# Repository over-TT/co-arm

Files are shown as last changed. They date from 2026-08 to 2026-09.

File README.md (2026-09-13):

# co-arm

3D-printed four-joint camera arm that Codex can see through and move.

A Raspberry Pi handles the camera and commands. An ESP32 Arm HAT talks to four
serial servos. The Base turns through a 4:1 set of 3D-printed gears.

**Status:** working prototype. Codex has moved the real arm and captured the
desk through its camera. The dashboard, Pi code, ESP32 firmware, simulator,
Codex tools, and 12 printable parts are here. The last build details and public
demo media are still coming.

## Start here

- **Try the software:** [open the dashboard without hardware](docs/QUICKSTART.md).
- **Connect an existing arm:** [check the setup and connect it](docs/SETUP_WITH_CODEX.md#existing-arm-short-path).
- **Build your own:** start with the [parts and assembly guide](docs/ASSEMBLY.md).
  The bearing, fastener, print, wiring, and power details still need finishing.
- **See what is proven:** [status and evidence](docs/STATUS.md),
  [known limitations](docs/KNOWN_LIMITATIONS.md).

---

## Why I built it this way

I wanted Codex to do something physical, not just spit out servo angles. It
should be able to look at my desk, work out a move, move the arm, then look
again and see what happened.

The Pi handles the camera and the bigger commands. The ESP32 stays close to the
servos and handles the fast communication. The dashboard and Codex use the same
route to the arm, so I can test a move myself and let Codex use the exact same
system.

The Base uses a 4:1 gear set I printed. It trades some speed for more output
torque and finer movement. An early version tracked the Base by adding up
relative moves. That eventually lost the real position, so I switched to the
servo's own absolute multi-turn reading and kept a physical zero mark.

That failure shaped the rest of the project too: show the move first, run it,
then read the joints and camera again. Less guessing, more checking what the
real arm actually did.

---

## The build

| Part | Reference build |
| --- | --- |
| Joints | Base, Shoulder, Elbow, and Camera |
| Main servos | 3 x ST3215/STS-family serial-bus servos |
| Camera servo | SC09/SCS-family serial-bus servo |
| Base drive | 3D-printed 4:1 gear reduction |
| Main computer | Raspberry Pi 4 |
| Servo controller | ESP32 on Waveshare Bus Servo Driver HAT (A) |
| Camera | Raspberry Pi Camera Module 3 Wide / IMX708 |
| Arm lengths | 180 mm upper arm, 220 mm elbow-to-camera tip |
| Arm HAT firmware | `arm-hat-2.7.2` |

The Camera joint only aims the sensor. Shoulder and Elbow place it. Base turns
the whole arm around the desk.

---

## How it works

```mermaid
flowchart LR
    USER["Dashboard or Codex"] --> PI["Raspberry Pi"]
    PI --> CAM["Camera"]
    PI --> HAT["ESP32 Arm HAT"]
    HAT --> SERVOS["Four serial servos"]
    SERVOS --> HAT
    SIM["Isaac Sim"] -. same arm interface .-> USER
```

The dashboard and Codex both send moves to the Pi. The Pi works out the joint
targets and passes them to the ESP32. The ESP32 talks to the servos and sends
their positions back. The camera gives a separate look at what happened.

Codex gets useful arm actions such as **look**, **preview**, **move**, and
**release**. It does not need to build raw servo packets or know register
addresses. A preview does not move anything; it just shows the planned joint
targets and path before they are sent.

The simulator uses the same general route, so most of the software can be run
without the real arm connected.

---

## Repo

- [`software/dashboard/`](software/dashboard/) — the standalone arm dashboard.
- [`software/python/robot_gateway/`](software/python/robot_gateway/) — the Pi
  code for the arm and camera.
- [`software/firmware/`](software/firmware/) — the ESP32 Arm HAT firmware.
- [`software/python/arm_mcp/`](software/python/arm_mcp/) and
  [`software/plugin/`](software/plugin/) — the tools Codex uses to work with
  the arm.
- [`software/python/arm_sim/`](software/python/arm_sim/) — the Isaac Sim model
  and simulator bridge.
- [`software/operations/`](software/operations/) — setup, deployment, status,
  recovery, and build scripts.
- [`hardware/3mf/`](hardware/3mf/) — all 12 current printed parts, including
  both Base gears, the arm links, servo mounts, and camera pieces.
- [`hardware/`](hardware/README.md) — BOM and the rest of the mechanical and
  electrical build files.
- [`docs/`](docs/README.md) — setup, build notes, history, troubleshooting, and
  deeper technical details.
- [`docs/SETUP_WITH_CODEX.md`](docs/SETUP_WITH_CODEX.md) — the full path from a
  clean checkout to simulation or a real arm.

[`software/SOURCE_INDEX.json`](software/SOURCE_INDEX.json) is the quick map for
an agent or developer looking for a particular piece of source.

---

## Run it

The [quickstart](docs/QUICKSTART.md) gets the dashboard running locally with
Python, Node, and pnpm. You can explore it before connecting an arm; movement
and camera controls need a configured gateway.

For the next step, use the full setup guide:

- [Run the source checks](docs/SETUP_WITH_CODEX.md#1-clone-and-validate-without-hardware).
- [Run the Isaac Sim arm](docs/SETUP_WITH_CODEX.md#3-run-the-isaac-sim-arm).
- [Connect an existing real arm](docs/SETUP_WITH_CODEX.md#existing-arm-short-path).

Isaac Sim and the ESP32 build tools are separate installs. The dashboard does
not include a fake camera feed or a simulator that runs in the browser.

---

## Put Codex on it

Open the repo in Codex and paste this:

```text
Help me run co-arm. Read AGENTS.md and docs/SETUP_WITH_CODEX.md first. Check
whether I am using source only, Isaac Sim, or the real arm, then take the
matching path. For a configured real arm, read its current state, show the move,
run it, and check the joints or camera afterward. Treat the physical task I ask
for as the go-ahead for its normal steps. Keep updates short and stop only if a
real fault or missing physical fact changes the job.
```

The external MCP/plugin is the supported Codex connection. It talks to the same
Pi arm service as the dashboard.

---

## Build the real arm

Start with [`docs/ASSEMBLY.md`](docs/ASSEMBLY.md) and
[`docs/COMMISSIONING.md`](docs/COMMISSIONING.md).

The short version:

1. print and assemble the mechanism, including the 4:1 Base gears;
2. wire the Pi, camera, Arm HAT, and four servos;
3. give every servo the correct ID;
4. mark the physical Base zero;
5. calibrate one joint at a time;
6. test small moves before coordinated motion;
7. connect the dashboard or Codex after the arm works normally.

The reference software and all 12 current printable parts are included. To
finish the build package, I still need to add:

- the large Base bearing details;
- final print settings and the screw/insert list;
- an as-built wiring diagram and pinout;
- the final power details;
- assembly photos, a hero photo, and a short real-arm demo.

See [`docs/STATUS.md`](docs/STATUS.md) for what has actually been checked on the
reference arm.

---

## License

Made by [over-TT](https://github.com/over-TT). Available for noncommercial use:

- **Software and firmware:** [PolyForm Noncommercial 1.0.0](LICENSE).
- **Printable designs, documentation, and media:** [CC BY-NC 4.0](LICENSES/CC-BY-NC-4.0.txt).

Commercial use requires separate permission. See [Licensing](LICENSING.md) for
the exact scope, attribution, and third-party terms. This is source-available
software, not an OSI open-source release.

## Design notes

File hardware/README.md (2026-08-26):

# Hardware files

This directory is the landing area for the co-arm physical design package.

```text
hardware/
|-- bom/                  Exact purchased and manufactured parts
|-- cad/
|   |-- native/           Editable source CAD
|   `-- step/             Neutral solid exports
|-- 3mf/                  Current 3D-printed parts
|-- stl/
|   `-- print-ready/      Verified, intentionally oriented print candidates
|-- drawings/             Dimensioned part and assembly drawings
`-- electronics/
    |-- schematics/       Electrical intent and power distribution
    `-- wiring/           Point-to-point harness and connector documentation
```

Start with [`../docs/HARDWARE.md`](../docs/HARDWARE.md), then follow the export
and naming rules in [`../docs/CAD_AND_STL.md`](../docs/CAD_AND_STL.md).

## When adding more build files

1. Add label photographs and use them to finish `bom/bom.csv`.
2. Put new printed parts in `3mf/` with the same clean naming style.
3. Add editable CAD to `cad/native/`.
4. Export the matching revision to `cad/step/`.
5. Export printable parts to `stl/`; promote only checked parts to
   `stl/print-ready/`.
6. Add revision-matched drawings to `drawings/`.
7. Add electrical source files and readable exports to
   `electronics/schematics/` and `electronics/wiring/`.
8. Update the assembly documentation only after checking the files against the
   physical arm.

Do not add credentials, local network addresses, private filesystem paths,
unwanted serial numbers, or personal metadata. Do not add a license or
third-party attribution unless ownership and the exact terms have been
confirmed.

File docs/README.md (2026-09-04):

# Documentation map

## Start here

- [Quickstart: open the dashboard without hardware](QUICKSTART.md)
- [Connect an existing arm](SETUP_WITH_CODEX.md#existing-arm-short-path)
- [Full setup runbook, with or without Codex](SETUP_WITH_CODEX.md)
- [Status and evidence](STATUS.md)
- [Open questions](OPEN_QUESTIONS.md)
- [Known limitations](KNOWN_LIMITATIONS.md)
- [Release checklist](RELEASE_CHECKLIST.md)
- [Release review and remaining blockers](RELEASE_REVIEW.md)
- [Release notes and X draft](LAUNCH_DRAFT.md)
- [Owner handoff](OWNER_HANDOFF.md)

For a new physical build, start with [Assembly](ASSEMBLY.md), the
[hardware inventory](HARDWARE.md), and [Commissioning](COMMISSIONING.md).
The printable parts are included; the remaining build gaps are listed in
[Known limitations](KNOWN_LIMITATIONS.md).

## Build and hardware

- [Hardware inventory](HARDWARE.md)
- [Mechanical design](MECHANICAL.md)
- [Electronics and power](ELECTRONICS.md)
- [Assembly](ASSEMBLY.md)
- [CAD and STL exports](CAD_AND_STL.md)
- [Commissioning](COMMISSIONING.md)

## Software and operation

- [Software architecture](SOFTWARE_ARCHITECTURE.md)
- [Control and safety](CONTROL_AND_SAFETY.md)
- [Codex integration](CODEX_INTEGRATION.md)
- [AI context contract](AI_CONTEXT.md)
- [Vision workflow](VISION.md)
- [Troubleshooting](TROUBLESHOOTING.md)
- [Public source boundary](SOURCE_RELEASE_PLAN.md)

## Project record

- [Public engineering history](HISTORY.md)
- [Proof log](PROOF_LOG.md)
- [Roadmap](ROADMAP.md)
- [Media guide](MEDIA_GUIDE.md)
- [Provenance and privacy](PROVENANCE.md)

For the project record and the exact boundary between publishable evidence and
local runtime data, use [History](HISTORY.md) and
[Provenance and privacy](PROVENANCE.md).

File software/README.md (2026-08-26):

# ARM software

This is the executable, ARM-only source boundary. Its project root is this
`software/` directory; runtime state belongs in ignored `software/runtime/`.

| Folder | Contents |
| --- | --- |
| `dashboard/` | Standalone Vite/React Control Center, calibration, camera, and bounded Live Follow |
| `python/web_backend/` | Loopback-only FastAPI host and explicit SIM/REAL routing |
| `python/robot_gateway/` | Raspberry Pi gateway, camera, serial controller, calibration, motion policy, and tests |
| `python/arm_sim/` | Core authenticated Isaac bridge, digital-twin assets, viewer, gateway, and tests |
| `python/arm_mcp/` | Typed ARM MCP server |
| `firmware/` | Arm HAT firmware/library, protocol fixtures, and host tests |
| `operations/` | Parameterized deployment, recovery, status, service, firmware-build, and simulator helpers |
| `plugin/` | Repo-local Codex marketplace, setup/runtime skills, and machine-local MCP setup guidance |

[`SOURCE_INDEX.json`](SOURCE_INDEX.json) maps the canonical entrypoints.
[`SOURCE_MANIFEST.json`](SOURCE_MANIFEST.json) records every releasable software
file and digest; regenerate it from the repository root with
`python tools/build_source_manifest.py` after an intentional source change.

Quick verification from the repository root:

```powershell
python -m venv .venv
.\.venv\Scripts\python.exe -m pip install --requirement ".\software\python\requirements.lock"
.\.venv\Scripts\python.exe -m pip install --no-deps --editable ".\software\python"

Set-Location software\python
..\..\.venv\Scripts\python.exe -m pytest -q -p no:cacheprovider
..\..\.venv\Scripts\python.exe -m pytest -q -p no:cacheprovider ..\firmware\tests\test_arm_hat_controller_v1.py

Set-Location ..\dashboard
pnpm install --frozen-lockfile
pnpm test
pnpm build
Set-Location ..\..
```

Run the dashboard with `.\.venv\Scripts\python.exe -m web_backend`. A clean
checkout starts without a physical or simulated gateway; pass an explicit
loopback URL and local token-file pair to enable one. The supported agent path
is the repository contract plus external plugin; Codex binaries, authentication,
installed plugin configuration, live credentials, retained frames, databases,
device backups, generated scenes, and toolchains are deliberately not bundled.

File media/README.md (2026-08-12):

# Media

Only reviewed, public-safe exports belong in this tracked tree.

- `photos/overview/` — complete-arm and scale views.
- `photos/assembly/` — staged construction and cable-routing views.
- `photos/details/` — labels, joints, gearing, camera, HAT, and power details.
- `diagrams/` — original SVG/PNG diagrams and captions.
- `video/` — small approved clips or link manifests.
- `raw/` — ignored intake folder for unreviewed originals; create it locally.

Follow [`docs/MEDIA_GUIDE.md`](../docs/MEDIA_GUIDE.md). Remove metadata and
review faces, screens, addresses, serials, QR codes, and unrelated desk details
before copying anything out of `raw/`.

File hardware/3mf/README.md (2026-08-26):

# 3D-printed parts

These are the parts from my current arm.

## Parts

- `co-arm_base_main-body_r01.3mf` — Base with the large gear built in.
- `co-arm_base_servo-gear_r01.3mf` — Small gear for the Base servo.
- `co-arm_base_bearing-bottom_r01.3mf` — Sits underneath the large Base bearing.
- `co-arm_base_shaft-base_r01.3mf` — Sits on top of the bearing.
- `co-arm_base_level-2-platform_r01.3mf` — Bolts to the Shaft Base and carries the lower-arm servo.
- `co-arm_shoulder_servo-mount_r01.3mf` — Mount for the lower-arm servo.
- `co-arm_shoulder_lower-link_r01.3mf` — Lower arm link.
- `co-arm_elbow_upper-link_r01.3mf` — Upper arm link.
- `co-arm_elbow_servo-cover_r01.3mf` — Cover for the top servo.
- `co-arm_camera_servo-mount_r01.3mf` — Holds the camera servo at the end of the arm.
- `co-arm_camera_holder_r01.3mf` — Holds the camera.
- `co-arm_camera_cover_r01.3mf` — Closes the camera holder.

## Build order

1. Put the bearing-bottom piece in the Base.
2. Fit the large bearing above it.
3. Put the Shaft Base on the bearing.
4. Fit the lower-arm servo and its mount before bolting on the Level 2 platform.
5. Mesh the small servo gear with the large Base gear.
6. Add the lower link, upper link, and top-servo cover.
7. Fit the camera-servo mount, camera holder, camera, and camera cover.

## Still needed

- large bearing details;
- heat-set insert and M3 screw list;
- print settings;
- assembly photos.

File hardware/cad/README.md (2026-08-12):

# CAD

Store editable sources in [`native/`](native/) and neutral solid exports in
[`step/`](step/). Do not mix STL meshes, slicer projects, drawings, or firmware
into these folders.

Follow [`../../docs/CAD_AND_STL.md`](../../docs/CAD_AND_STL.md) for the required
millimetre units, coordinate frame, naming, `rNN` revisions, STEP settings, and
matched-export checklist.

Minimum release set:

- top-level zero-position assembly;
- one file/component per manufactured part;
- purchased actuator/controller reference geometry where licensing permits;
- named Base, Shoulder, Elbow, and Camera axes;
- named work-surface and tool/camera datums;
- revision-matched STEP and drawings.

Do not infer ownership or apply a license to imported vendor models until their
source and terms are documented.

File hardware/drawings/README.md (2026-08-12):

# Mechanical drawings

Put revision-matched part and assembly drawings here. Prefer a readable PDF for
every released drawing and include the editable/source drawing when available.

Use the same basename as CAD:

```text
co-arm_<subsystem>_<part-name>[_<variant>]_rNN.pdf
```

Part drawings should state units, projection, material/process when confirmed,
datums, overall and fit-critical dimensions, holes/threads/inserts, tolerances,
orientation, and quantity. Assembly drawings should add exploded views, BOM
balloons, fastener stack order, joint zero views, gear timing/mesh, and cable
routing.

Do not invent material, tolerance, fastener, or torque values. Leave an explicit
`TODO (owner verification)` note until the as-built part is inspected.

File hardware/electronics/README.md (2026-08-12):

# Electronics design files

This folder separates electrical intent from physical harness construction:

- [`schematics/`](schematics/) — power domains, protection, interfaces, and
  connector pin definitions;
- [`wiring/`](wiring/) — point-to-point cables, connector orientation, wire
  gauge/color/length, labels, and routing.

Read [`../../docs/ELECTRONICS.md`](../../docs/ELECTRONICS.md) first. The current
repository does not yet contain a verified pinout. Do not infer wiring from
software signal names, connector shape, or wire color.

The candidate 12 V, 7.5 A supply, camera-servo voltage/regulator, fusing,
grounding, polarity, wire ratings, and hardware E-stop/disconnect all require
owner verification before a reproducible wiring guide can be released.

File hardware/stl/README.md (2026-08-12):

# STL exports

Put revision-matched printable-part meshes here. STL has no dependable unit
metadata, so every mesh must be exported numerically in **millimetres** and
checked against its drawing/bounding box after re-import.

Use:

```text
co-arm_<subsystem>_<part-name>[_<variant>]_rNN.stl
```

Requirements:

- one manufactured part per file unless a multi-part print is intentional;
- binary STL;
- manifold/watertight mesh with outward normals;
- no self-intersections, duplicate shells, supports, raft, brim, or G-code;
- initial chordal tolerance 0.10 mm or finer and angular tolerance 1 degree or
  finer, with tighter settings where functional geometry needs it;
- reopened scale and bounding-box check.

These are geometry exports, not automatically proven print profiles. See
[`print-ready/`](print-ready/) and
[`../../docs/CAD_AND_STL.md`](../../docs/CAD_AND_STL.md).

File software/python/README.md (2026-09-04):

# Python stack

This directory contains only the ARM-specific Python packages:

- `robot_gateway`: Raspberry Pi API, camera, calibration, safety, motion, and
  live-follow control;
- `arm_sim`: source-only Isaac Sim model, bridge, scene, and contract tests;
- `arm_mcp`: typed MCP tools that talk to a configured gateway;
- `web_backend`: the ARM-only local dashboard proxy and supporting services.

From the repository root, create the canonical project environment, install the
stack, and run its tests with that exact interpreter:

```powershell
python -m venv .venv
.\.venv\Scripts\python.exe -m pip install --requirement ".\software\python\requirements.lock"
.\.venv\Scripts\python.exe -m pip install --no-deps --editable ".\software\python"
Set-Location software\python
..\..\.venv\Scripts\python.exe -m pytest -q -p no:cacheprovider
Set-Location ..\..
```

The lock includes the test extra: pytest, NumPy, and headless OpenCV. The
simulator's camera-policy tests exercise real pixel arrays and a JPEG round
trip without launching Isaac. These host-test dependencies are not added to
the Pi requirements and do not replace Isaac's own Python environment.

Build the frontend in `../dashboard`, then start the local UI with no live
backend:

```powershell
.\.venv\Scripts\python.exe -m web_backend
```

Add one or both complete credential pairs to expose REAL or SIM. Token files
stay outside Git and are never sent to the browser:

```powershell
.\.venv\Scripts\python.exe -m web_backend `
  --real-url http://127.0.0.1:8787 `
  --real-token-file <absolute-owner-only-token-path>
```

The server binds only to `127.0.0.1`, validates the browser action token, and
requires each selected backend on every ARM request. Agent access uses the
separate `arm_mcp` package and an explicit machine-local MCP configuration.
Isaac Sim is started by `../operations/scripts/run_arm_sim.py`; its installation
path, tokens, logs, and generated scene remain local and outside version control.

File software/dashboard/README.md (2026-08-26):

# Co-Arm dashboard

This directory is the standalone React/Vite frontend for the Co-Arm itself. It
contains Overview, guarded Control, bounded Live Follow, camera, calibration,
commissioning, Guide, SIM/REAL selection, and the visible Isaac Sim launcher.

Agent assistance stays outside the dashboard. Open the repository root in
Codex, follow `AGENTS.md` and `docs/SETUP_WITH_CODEX.md`, then configure the
portable plugin at `software/plugin/plugins/arm-alliance/` to help build, set
up, and run the arm through the Raspberry Pi-backed stack.

The dashboard keeps the same-origin API contract as the integrated ARM
application. It expects the Co-Arm backend to serve the `/api/arm` and
`/api/camera` routes. The frontend deliberately remains useful
in its offline state when those routes are unavailable; it does not simulate a
successful hardware connection.

## Run locally

```sh
pnpm install --frozen-lockfile
pnpm dev
```

Open the URL printed by Vite. For live backend access, serve the built files
from the ARM backend or put both behind a same-origin reverse proxy.

## Verify

```sh
pnpm test
pnpm build
```

The production output is written to `dist/` and is intentionally ignored by
Git.

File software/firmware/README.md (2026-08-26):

# ARM firmware

This directory contains the ESP32 Arm HAT firmware and its host-side tests:

- `esp32/arm_hat_controller/` — the ESP32 Arm HAT sketch;
- `libraries/ArmHatController/` — bounded servo protocol and safety runtime;
- `tests/` — Arm HAT C++ host tests, Arduino stubs, and sanitized fixtures;
- `ARM_HAT_CONTROLLER_V1.md` — the current host/HAT protocol contract.

Generated BIN, ELF, MAP, object, and factory-backup files are not part of the
source release. The compile helper uses a caller-supplied system Arduino CLI,
requires the pinned ESP32 core, writes to an explicit build directory, and
never uploads firmware:

```powershell
./operations/scripts/compile-firmware.ps1 `
  -ArduinoCli <path-to-arduino-cli> `
  -BuildRoot <temporary-build-directory>
```

Run the source/host tests from `software/`:

```powershell
$env:PYTHONPATH = "python"
python -m pytest -q firmware/tests/test_arm_hat_controller_v1.py
```

A passing build or host test is software evidence. It does not prove a flash,
controller identity, servo-bus health, torque state, or physical motion.

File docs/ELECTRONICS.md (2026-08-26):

# Electronics and wiring

This page captures the known electronic architecture and defines what must be
verified before a public wiring guide can be called complete. No connector
pinout is published yet because the as-built harness has not been traced and
photographed end to end.

## Known functional blocks

| Block | Recorded device | Role |
| --- | --- | --- |
| Gateway | Raspberry Pi 4 | Network/API host and camera capture |
| Camera | Raspberry Pi Camera Module 3 Wide (`IMX708`) | Powered-autofocus image source over the Pi camera interface |
| Motion controller | Waveshare Bus Servo Driver HAT (A), SKU 27577 | Integrated ESP32, host-UART endpoint, and serial-servo bus control |
| Main joints | 3 x ST3215/STS-family serial-bus servos | Base, Shoulder, and Elbow |
| Camera joint | SC09/SCS-family serial-bus servo | Camera pitch |
| Candidate servo supply | 12 V, 7.5 A, 90 W nominal | Candidate source for the high-power servo rail only |

Exact model labels, board revisions, connector variants, and voltage limits must
be transcribed from the physical components into the BOM.

## Logical signal topology

```text
Raspberry Pi 4
  +-- camera interface ---------------- Camera Module 3 Wide / IMX708
  |
  `-- UART, 115200 baud ---------------- ESP32 on Waveshare HAT (A)
                                              |
                                              `-- half-duplex serial servo bus,
                                                  1 Mbps
                                                    +-- ID 1 Base
                                                    +-- ID 2 Shoulder
                                                    +-- ID 3 Elbow
                                                    `-- ID 4 Camera
```

This is a logical topology. The connector order, wire colors, pin numbers,
physical daisy-chain order, branch locations, and ground paths are **TODO (owner
verification)**. Do not turn the diagram above into a cable without consulting
the board/servo documentation and checking the physical harness with power off.

## Servo addressing

The current logical assignment is:

| ID | Joint | Working family/model |
| ---: | --- | --- |
| 1 | Base | ST3215/STS-family |
| 2 | Shoulder | ST3215/STS-family |
| 3 | Elbow | ST3215/STS-family |
| 4 | Camera | SC09/SCS-family |

Serial-bus servos may ship with the same default ID. Two devices answering one
address can make the bus unreadable. Verify or change an ID with only one
uncommissioned servo connected, then label both the servo and its cable before
adding it to the shared bus.

The camera servo belongs to a related but not necessarily identical protocol
family. Its exact label, voltage, byte ordering, and compatible control profile
must be verified rather than inferred from the three main servos.

## Power domains

Treat these as separate domains until the as-built circuit proves otherwise:

1. Raspberry Pi logic power.
2. ESP32/HAT logic power.
3. 12 V candidate rail for the ST3215/STS-family actuators.
4. Camera-servo rail, potentially regulated to a different voltage.
5. Signal/common reference between the controller and servo bus.

Never apply the candidate 12 V rail directly to the Raspberry Pi. Do not apply
12 V to the SC09/SCS-family servo until its exact label and electrical rating
are confirmed. The presence, model, setting, and load capability of any
step-down converter remain undocumented.

### Candidate supply is not yet an approved supply

`12 V x 7.5 A = 90 W` is only the nameplate nominal value. Approval requires:

- exact supply model and trustworthy output rating;
- connector type and verified centre/pin polarity;
- measured no-load and loaded voltage;
- simultaneous-axis peak current or a conservative measured bound;
- suitable wire gauge, connector current rating, branch distribution, and
  temperature rise;
- fuse/protection strategy and fault-current path;
- headroom for transient/stall conditions without voltage collapse;
- confirmation that logic power remains stable during joint starts/stops.

Do not size the system by adding advertised servo torque values or by assuming
all actuators draw the same current.

## STOP and emergency isolation

The software stack has a STOP state and torque-control safeguards. Those are
important controls, but they are not proof of a physical emergency stop. A
public build guide must distinguish:

- **software STOP:** a controller/gateway state that commands or prevents
  motion while electronics remain powered;
- **hardware E-stop/disconnect:** a reachable, intentional method that removes
  actuator power or otherwise puts the machine in a defined safe state without
  depending on software or communications.

- **TODO (owner verification):** state whether a physical E-stop or latched
  servo-power disconnect exists and document exactly what conductors it opens.
- **TODO (owner verification):** document what happens to each link after
  actuator power is removed; gravity may make an elevated arm fall or sag.

## Required wiring documentation

Add final files under:

- [`hardware/electronics/schematics/`](../hardware/electronics/schematics/) for
  electrical intent, power domains, protection, and connector pin numbers;
- [`hardware/electronics/wiring/`](../hardware/electronics/wiring/) for the
  physical harness, cable IDs, lengths, routing, and photographs/diagrams.

Every connector in a released drawing should have:

- unique reference designator (`J1`, `J2`, ...);
- mating connector family and part number;
- pin number, signal name, nominal voltage, maximum expected current, and wire
  color/gauge;
- polarity/keying view and an explicit statement of the viewing side;
- destination reference and cable label;
- revision and date.

## Power-off wiring verification checklist

1. Disconnect all external power and mechanically support raised links.
2. Photograph the complete system before moving wires.
3. Trace one conductor at a time; do not rely only on color.
4. Confirm continuity and absence of shorts with an appropriate meter.
5. Record connector views as `mating face` or `wire side`.
6. Verify supply polarity at the disconnected load connector.
7. Verify the regulator output independently before attaching a servo.
8. Reconnect one power domain at a time with current limiting when appropriate.
9. Check idle voltage/current and temperature before enabling motion.
10. Update the schematic, wiring drawing, BOM, and photo captions together.

## Unresolved electrical record

- **TODO (owner verification):** Pi 4 board revision, RAM, storage, power
  supply, and cooling.
- **TODO (owner verification):** exact HAT revision and all switch/jumper
  positions.
- **TODO (owner verification):** complete connector pinout and physical bus
  order.
- **TODO (owner verification):** exact labels and electrical ratings of all
  four servos.
- **TODO (owner verification):** supply brand/model, mains input rating,
  output tolerance, DC connector, and polarity.
- **TODO (owner verification):** camera-servo regulator/step-down model,
  adjustment, measured output, current capability, and thermal margin.
- **TODO (owner verification):** fuse type/rating/location, over-current and
  reverse-polarity protection, grounding, wire gauge, strain relief, and cable
  shielding/routing.
- **TODO (owner verification):** hardware E-stop/disconnect and safe-state
  behavior.
- **TODO (owner verification):** measured idle, single-axis, coordinated, and
  worst-observed current/voltage data.

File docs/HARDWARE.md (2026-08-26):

# Hardware

This is the hardware used by the current co-arm build.

## Main parts

| Part | Current build | Notes |
| --- | --- | --- |
| Main computer | Raspberry Pi 4 | Runs the camera and arm gateway |
| Servo controller | Waveshare Bus Servo Driver HAT (A) with ESP32 | Connects the Pi to the servo bus |
| Base, Shoulder, Elbow | 3 x ST3215/STS-family serial servos | Exact label suffixes still need photos |
| Camera joint | SC09/SCS-family serial servo | Exact label still needs a photo |
| Camera | Raspberry Pi Camera Module 3 Wide / IMX708 | Mounted upside down; corrected in software |
| Printed mechanism | 12 current parts | Both Base gears, Base stack, links, mounts, and camera pieces |
| Servo power | 12 V, 7.5 A supply on the reference arm | Final power and wiring details are still being added |

The full parts list is in [`hardware/bom/bom.csv`](../hardware/bom/bom.csv).

## Four moving joints

1. **Base** turns the whole arm around the desk.
2. **Shoulder** moves the lower link.
3. **Elbow** moves the upper link.
4. **Camera** aims the camera without moving the rest of the arm.

The Base uses two printed gears: 52 teeth on the Base and 13 teeth on the servo.
That gives a 4:1 reduction for more output torque and finer movement. Both files
are in [`hardware/3mf/`](../hardware/3mf/), together with the other 10 printed
parts.

## Dimensions used by the software

| Measurement | Value |
| --- | ---: |
| Base pivot height | 60 mm |
| Shoulder to Elbow | 180 mm |
| Elbow to camera offset | 180 mm |
| Camera offset | 40 mm |
| Elbow to camera tip | 220 mm |

These are the dimensions used by the current arm software. I still need to
measure the final printed assembly and add the remaining hardware details.

## Connections

```text
Camera -> Raspberry Pi
Raspberry Pi -> ESP32 Arm HAT
Arm HAT -> Base / Shoulder / Elbow / Camera servos
```

The Pi talks to the HAT at 115200 baud. The HAT talks to the servos at 1 Mbps.
The servo IDs are `1 / 2 / 3 / 4` for Base, Shoulder, Elbow, and Camera.

See [`ELECTRONICS.md`](ELECTRONICS.md) for the current wiring notes and
[`ASSEMBLY.md`](ASSEMBLY.md) for the physical build order.

## Still to add

- exact servo labels and Raspberry Pi revision;
- large Base bearing details;
- heat-set insert and M3 screw list;
- print settings;
- final power and wiring diagram;
- tested joint limits and payload.

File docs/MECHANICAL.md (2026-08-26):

# Mechanical design

co-arm is a four-joint printed camera arm. The Base, gears, links, servo mounts,
covers, and camera holder are all part of the build.

## Joint layout

| Joint | What it moves | Servo ID |
| --- | --- | ---: |
| Base | Turns the whole arm | 1 |
| Shoulder | Lower arm link | 2 |
| Elbow | Upper arm link | 3 |
| Camera | Camera angle | 4 |

The Camera joint only aims the sensor. Shoulder and Elbow place it, and Base
turns the whole mechanism.

## Printed Base

The main Base print has the 52-tooth gear built into it. A separate 13-tooth
gear fits the Base servo, giving the arm its 4:1 reduction.

From bottom to top, the Base stack is:

1. Base with the large gear;
2. bearing-bottom piece;
3. large bearing;
4. Shaft Base;
5. Level 2 platform with the lower-arm servo and mount.

## Arm and camera

The lower link runs from the lower-arm servo to the next joint. The upper link
runs from there to the camera end. The top-servo cover closes the upper servo
area.

At the end of the upper link, the camera-servo mount holds the camera servo. The
camera holder attaches to that servo, and the camera cover closes the holder.

All 12 files are listed in
[`hardware/3mf/README.md`](../hardware/3mf/README.md).

## Dimensions used by the software

| Measurement | Value |
| --- | ---: |
| Base pivot height | 60 mm |
| Shoulder to Elbow | 180 mm |
| Elbow to camera offset | 180 mm |
| Camera offset | 40 mm |
| Elbow to camera tip | 220 mm |

These are the dimensions used by the current arm software. I still need to
measure the final printed assembly and add the remaining hardware details.

## Joint zero positions

- Base zero lines up with the physical mark on the Base.
- Shoulder zero points the lower link straight up.
- Elbow zero is the folded-middle position used by the current arm model.
- Camera zero looks along the upper link.

With torque off, Shoulder and Elbow can sag. Hold the arm or rest it on
something before releasing torque.

## Still to add

- large Base bearing and remaining shaft/horn details;
- heat-set insert and M3 screw list;
- material and print settings;
- final joint limits, cable clearance, weight, and tested payload.

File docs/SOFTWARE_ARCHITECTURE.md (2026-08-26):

# Software architecture

This page shows how the dashboard, Codex, Pi, ESP32, camera, and servos fit
together.

## Why I split it this way

The Pi is good at Linux, networking, Python, and the camera. The ESP32 is better
placed for the fast servo-bus work. Keeping those jobs separate means a slow
browser or camera request does not have to become servo timing.

The dashboard and Codex both use the same Pi route. I can try a move myself in
the dashboard, then let Codex use the same system instead of maintaining a
second robot controller just for AI.

## System at a glance

co-arm is a four-joint desk arm with a camera at the distal end. Control is
split deliberately across three computers:

```mermaid
flowchart LR
    UI["Arm dashboard"] --> B["Dashboard backend"]
    MCP["Codex arm tools"] --> G["Raspberry Pi"]
    B --> G
    G --> C["Pi camera"]
    G -->|"joint commands"| H["ESP32 Arm HAT"]
    H -->|"servo bus"| S["Base, Shoulder, Elbow, Camera servos"]
```

| Part | Job |
| --- | --- |
| Dashboard / Codex | Shows the arm and asks it to look, preview, or move |
| Laptop backend | Serves the dashboard and selects the simulator or real arm |
| Raspberry Pi | Runs the camera, stores calibration, and works out joint targets |
| ESP32 Arm HAT | Talks to the four servos quickly and reads their positions back |
| Smart servos | Move each joint and report their local state |

Both the dashboard and Codex reach the arm through the Pi. Neither needs to
build raw servo packets.

## The four driven joints

1. **Base** — yaw around the vertical axis. The reference build uses an
   ST3215-family servo and 3D-printed 52:13 gears for 4:1 reduction. Firmware
   reads the servo's absolute multi-turn position.
2. **Shoulder** — raises or lowers the upper arm and participates in planar
   inverse kinematics.
3. **Elbow** — changes distal reach and participates in planar inverse
   kinematics.
4. **Camera** — tilts the end-mounted camera. It is calibrated and driven like
   the other joints but is excluded from the arm endpoint IK chain.

Servo-bus identifiers and servo families are configuration, not discoverable
mechanical truth. A responding device must still be matched to the printed
servo label and physical joint during commissioning.

## Angles and arm dimensions

All public motion tools use calibrated **servo degrees**. The 2D scene uses a
radial/height plane measured in millimetres:

- Base pivot height: `60 mm`
- Upper arm length: `180 mm`
- Elbow-to-camera/tool-tip distance: `220 mm`
- Default floor keep-out height: `40 mm`
- Shoulder servo `0 deg`: upper arm points straight up
- Negative Shoulder: tilts the upper arm forward
- Elbow servo `0 deg`: folded mid-travel reference
- Elbow servo `90 deg`: arm is straight when Shoulder is `0 deg`
- Camera servo `0 deg`: optical ray follows the forearm
- Positive Camera: rotates the view downward

The dashboard/MCP model converts servo angles as follows:

```text
shoulder_model = shoulder_servo + 90 deg
elbow_model    = elbow_servo - 90 deg
forearm_angle  = shoulder_model + elbow_model
camera_ray     = forearm_angle - camera_servo
```

With `h = 60`, `L1 = 180`, and `L2 = 220` millimetres:

```text
elbow.x = L1 * cos(shoulder_model)
elbow.z = h  + L1 * sin(shoulder_model)
tip.x   = elbow.x + L2 * cos(forearm_angle)
tip.z   = elbow.z + L2 * sin(forearm_angle)
```

The physical camera is mounted inverted. The Pi applies a 180-degree transform
so newly delivered images are upright. The Base affects azimuth but not the 2D
height calculation; the Camera joint affects the optical ray but not endpoint
position.

## Base: native absolute multi-turn control

The current firmware line retains the native Mode-0 design introduced in 2.4
and is exported as `arm-hat-2.7.2`:
absolute multi-turn control:

1. The ST3215 is configured for its native extended-position phase and exposes
   one signed absolute motor coordinate while its volatile frame is intact.
2. The ESP32 validates fresh native samples and rejects evidence of a reset or
   continuity collapse; it preserves the older odometer-shaped wire contract
   without running the retired relative-step loop.
3. The Pi converts a calibrated output-joint angle through the external gear
   ratio into one signed absolute motor destination, and the servo's own
   Mode-0 position loop closes it.
4. Repeating the same goal is idempotent; a new goal replaces the previous
   destination instead of queuing relative hops.

The native extended coordinate is not persistent through every servo power or
continuity loss. When Base truth is unknown, stop, support the mechanism, align
the physical Base zero mark, and use the calibrated **Set zero here** workflow.
Never infer the missing output revolution from a single-turn reading. A Pi-only
process restart may preserve Base truth only when the still-running controller
proves the same boot and valid native frame.

## Command paths

The gateway exposes direct compatibility control plus reviewed plan/apply and
sequence paths. A separate bounded Live Follow mode exists only for deliberate
REAL-arm sessions.

### Plan/apply (preferred)

`arm_plan` is motionless. The Pi obtains a fresh measured snapshot, resolves
joint targets or planar tip IK, quantizes once, applies calibrated limits,
checks Base continuity, evaluates the complete Shoulder/Elbow sweep, and
returns:

- measured and resolved poses;
- a solid measured arm and dashed planned arm;
- warnings and lowest swept clearance;
- a short-lived, one-use plan identifier and digest.

The current implementation gives a plan a 30-second lifetime. Applying it
consumes it once. Before execution, the Pi rechecks controller boot continuity,
fresh telemetry, STOP, bus state, pending movement, calibration/configuration,
floor protection, plan digest, and start-pose drift (currently limited to
`2 deg`). A failed or replayed apply requires a new plan.

Plan acceptance is not arrival proof. Read measured state after the move.

### Sequence plan/apply

`arm_plan_sequence` resolves two to eight ordered waypoints without motion and
binds their carried-forward poses, segment sweeps, warnings, and clearance into
one digest. `arm_apply_sequence` revalidates live safety and proves each measured
arrival before dispatching the next waypoint. A returned route receipt is still
not visual proof of an object-level outcome.

### Live Follow

Live Follow controls only Shoulder and Elbow. The browser coalesces pointer
intent while an independent heartbeat maintains the Pi lease. The Pi
dispatches at most 20 Hz, the Arm HAT writes both goals as one grouped operation,
and fresh feedback is returned. Sessions are REAL-only, deliberate, and limited
to 30 seconds with a 400 ms input dead-man. Raw speed is limited to `1..2400`,
raw acceleration to `1..50`, and start-relative travel to `1..90 deg` per joint.
These are controller settings, not calibrated degrees per second.

### Direct move (compatibility)

`arm_move` sends one coordinated set of named joint targets and returns while
the joints may still be travelling. The Pi clamps calibrated travel and applies
its direct floor policy. This path remains useful for established workflows,
but plan/apply is the default when sweep review matters.

## Evidence path

The Pi camera is independent of the geometry model:

```text
measured telemetry -> arm_scene -> calculated geometry
camera capture      -> arm_look  -> real pixels
retained capture    -> arm_detail -> crop of the same pixels
```

`arm_scene` can prove the calculated pose and camera ray, not what is visible.
`arm_look` can prove only what appears in that capture. `arm_detail` makes no
movement and takes no new photograph; it crops a retained source image.

## State and persistence

Persisted arm configuration includes joint mapping, servo family, zero,
direction, travel limits, gear ratio, geometry, and related revision data.
Runtime state includes measured positions, torque authority, STOP, connection,
bus health, camera frames, plans, and Base continuity. Runtime state must never
be treated as durable memory.

Credentials and endpoint addresses belong in local deployment configuration,
not source control. Camera captures are bounded runtime evidence and are not
automatically project media.

## Public source layout

`software/` is the standalone project root:

- `software/dashboard/` — React/Vite Arm dashboard and tests
- `software/python/web_backend/` — loopback FastAPI dashboard runtime
- `software/python/robot_gateway/` — Raspberry Pi gateway and tests
- `software/python/arm_mcp/` — typed MCP server
- `software/python/arm_sim/` — core Isaac digital twin, bridge, and tests
- `software/firmware/` — Arm HAT, shared controller library, and host-side tests
- `software/plugin/` — repo-local Codex marketplace and portable skills
- `software/operations/` — service templates, deployment/diagnostic helpers,
  and simulator launcher

The FastAPI runtime can serve a built dashboard on loopback. Without a locally
configured gateway, REAL-arm routes fail closed. The supported agent path is
the external MCP/plugin plus the repository setup contract; the public runtime
does not bundle an embedded Codex binary, account, memory, or chat service. See
[`SOURCE_RELEASE_PLAN.md`](SOURCE_RELEASE_PLAN.md) for the explicit included and
excluded boundary.

## Proof boundary

- Source inspection proves what the checked-in implementation intends.
- Tests prove the tested software branch under their fixtures.
- A successful build proves compilation, not installation.
- A gateway health response proves that process path, not servo readiness.
- Live state proves telemetry at that moment.
- A target or accepted plan does not prove arrival.
- A camera image proves only its visible content.
- Physical reach, clearance, STOP latency, load, temperature, and repeatability
  require controlled tests on the assembled arm.

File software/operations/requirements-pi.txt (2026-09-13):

# Picamera2/libcamera are installed from Raspberry Pi OS apt packages, not pip.
fastapi==0.141.1
pydantic==2.13.5
pyserial==3.5
starlette==1.6.0
uvicorn==0.35.0

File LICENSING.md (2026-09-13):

# Licensing

Copyright (c) 2026 over-TT and contributors.

co-arm is available for noncommercial use under the licenses below. The owner
selected these terms on 2026-09-13. Commercial use outside the permissions of
the applicable license requires a separate agreement with the relevant rights
holders; contact [over-TT](https://github.com/over-TT).

## Scope

| Material | License |
| --- | --- |
| Software, firmware, scripts, tests, configuration, model URDF/JSON, and build/package metadata in `software/`, `tools/`, and `.github/` | [PolyForm Noncommercial 1.0.0](LICENSE) |
| Executable code snippets in documentation | [PolyForm Noncommercial 1.0.0](LICENSE) |
| Printable parts, CAD/design files, drawings, BOM, and other original material in `hardware/` | [CC BY-NC 4.0](LICENSES/CC-BY-NC-4.0.txt) |
| Documentation and prose, including Markdown files, agent/skill instructions, and this repository's root documents | [CC BY-NC 4.0](LICENSES/CC-BY-NC-4.0.txt) |
| Original photos, diagrams, and videos intentionally included in `media/`, unless a file has a separate notice | [CC BY-NC 4.0](LICENSES/CC-BY-NC-4.0.txt) |

These categories are separate grants, not a choice of either license for any
file. The documentation rule includes Markdown under `software/` and `.github/`;
executable snippets retain the software license. License texts retain their
publishers' own terms. An explicit third-party file notice takes precedence.

## What the terms mean

PolyForm Noncommercial permits its defined noncommercial purposes, personal
uses, and listed noncommercial organizations. Keep its license and required
notices with redistributed software. Read the full text for its exact grants.

CC BY-NC permits noncommercial sharing and adaptation with attribution, a link
to the license, and an indication of changes. Credit **co-arm by over-TT**, link
to [this repository](https://github.com/over-TT/co-arm), and retain any other
supplied creator notices. It licenses rights held by the licensor; it does not
grant third-party rights or patent/trademark permissions.

The noncommercial restriction means co-arm is **source-available**, not an
OSI-approved open-source or unrestricted open-hardware project. Neither
license is a warranty that an assembled arm or recovery procedure will work.

## Third-party material and contributions

Dependencies, vendor material, and other separately identified components keep
their original licenses. These terms apply only to rights the project and its
contributors can grant. See [Third-party notices](THIRD_PARTY_NOTICES.md) and
[Provenance](docs/PROVENANCE.md); compatible vendor hardware does not imply
permission to redistribute its firmware or CAD.

Contributors retain copyright and submit their contributions under the license
for the affected category. Identify imported or adapted material and preserve
its notices. See [Contributing](CONTRIBUTING.md).

Official texts: [PolyForm Noncommercial 1.0.0](https://polyformproject.org/licenses/noncommercial/1.0.0)
and [CC BY-NC 4.0](https://creativecommons.org/licenses/by-nc/4.0/).

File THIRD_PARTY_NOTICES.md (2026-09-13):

# Third-party notices

This repository contains project source and dependency manifests. Generated
dependency trees, vendor toolchains, firmware binaries, simulator installs, and
factory-firmware backups are not redistributed.

Project-owned material uses the category-specific noncommercial licenses in
[Licensing](LICENSING.md). Those licenses do not replace dependency or vendor
licenses. The license texts in `LICENSE` and `LICENSES/` are reproduced from
the official PolyForm Project and Creative Commons publications without changes.

## Python package dependencies

The standalone Python package declares FastAPI, HTTPX, Pillow, Pydantic,
pyserial, Starlette, and Uvicorn at runtime; setuptools and wheel build it, and
pytest, NumPy, and headless OpenCV run its host tests. Direct constraints are recorded in
`software/python/pyproject.toml`, while `software/python/requirements.lock`
records the exact Python 3.11 runtime/test graph used by source validation.
The Raspberry Pi deployment set is pinned separately in
`software/operations/requirements-pi.txt`. Dependency licenses and notices
still come from their upstream distributions.

## Dashboard dependencies

The dashboard declares React, React DOM, Vite, TypeScript, Vitest, jsdom,
Testing Library, axe-core, and their build/test support packages. The exact
resolved dependency graph is recorded in `software/dashboard/pnpm-lock.yaml`.
`node_modules/` and built output are local generated artifacts and must not be
committed.

## Firmware and simulation ecosystems

- ESP32 and Arduino-ESP32 identify the firmware target and toolchain family.
- Raspberry Pi, Picamera2, and libcamera are referenced for the gateway and
  Camera Module 3 Wide / IMX708 stack.
- Waveshare Bus Servo Driver HAT (A), ST3215, and SC09 identify reference
  hardware and compatible protocol families.
- NVIDIA Isaac Sim / Isaac Lab integration source is included, but NVIDIA
  software, assets, and toolchains are not bundled.

Product names and trademarks belong to their respective owners. Their use
describes compatibility and does not imply endorsement.

Before adding a copied source file, CAD model, image, binary, report asset, or
other third-party material, record its component, version, author, source,
license, modifications, and required notices here. Do not infer redistribution
permission from a public download or compatible product name.

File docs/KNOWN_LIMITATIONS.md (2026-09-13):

# Known limitations

- co-arm is still a working prototype.
- It positions a camera. No gripper or tool actuator is installed.
- All 12 current printed parts are here, but the bearing, fastener, print,
  wiring, and power details are not finished yet.
- With torque off or power removed, the Shoulder and Elbow can sag.
- The desk/floor check is a 2D software check, not full 3D collision sensing.
- The current dimensions and calibration come from the reference arm; another
  build will need its own measurements and zero positions.
- Camera autofocus and wide framing still need a close look when small details
  matter.
- On a real arm without a calibrated camera/mount/desk projection, pixels are
  framing evidence. They do not give reliable desk coordinates or a precise
  contact point. The kinematic camera tip is not a calibrated contact surface.
- Isaac Sim, Arduino/ESP32 tools, and device drivers are separate installs.
- The no-hardware quickstart opens the dashboard; it does not start Isaac or
  provide simulated joint readings or camera images.
- The Python wheel and dashboard build are separate artifacts. The quickstart
  uses an editable checkout so the backend can find the local frontend build.
- The setup and deployment examples are Windows/PowerShell-first. Other host
  environments need their own verification.
- Portable Pi recovery has local archive/provenance and restored-Base guard
  tests, but no validated replacement-device round trip. See the
  [release review](RELEASE_REVIEW.md) before planning supervised recovery.
- The Live startup lifecycle fix is locally tested. A fresh installed-stack
  run is still needed to establish physical responsiveness and stability.
- The dashboard uses the external Codex tools; it does not contain Codex by
  itself.
- Software uses PolyForm Noncommercial 1.0.0; designs, documentation, and media
  use CC BY-NC 4.0. Commercial use needs separate permission; see
  [Licensing](../LICENSING.md).

See [Status and evidence](STATUS.md) for dated software and reference-arm
results, the [release review](RELEASE_REVIEW.md) for unresolved findings, and the
[release checklist](RELEASE_CHECKLIST.md) for publication work.

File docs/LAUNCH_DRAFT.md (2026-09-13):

# Launch draft

Draft only. The owner authorized a public prototype source release under the
noncommercial terms in [Licensing](../LICENSING.md). Publish demo media only
after approval and verification of its actual outcome. Describe the project as
source-available for noncommercial use, not OSI open source.

## Release title

co-arm v0.1 — a four-axis desk camera arm

## Release summary

I built co-arm to give an agent a camera it can physically move around my desk.
It uses a Raspberry Pi, an ESP32 servo controller, printed parts, and a small
dashboard. Codex connects through typed tools to inspect state, preview a move,
and check the returned joint readings and camera image.

This release contains the focused software stack and 12 printable parts:
dashboard, Pi gateway, controller firmware, agent tools, simulator source, tests,
and setup/build notes. Start with the dashboard quickstart; it works without
connecting any hardware.

Software uses PolyForm Noncommercial 1.0.0; designs, documentation, and media
use CC BY-NC 4.0. Full build details and the physical recovery round trip remain
unfinished, as recorded in the release limitations.

It is an experimental reference build. The camera is not a calibrated depth
sensor, the arm has no gripper, and software tests do not establish mechanical
reliability. Keep any unfinished assembly or recovery items explicitly listed
in the released limitations.

## X post

> I built co-arm: a 3D-printed desk camera arm that Codex can move through typed
> tools. It previews a route, checks joint readings, and takes a real image.
>
> Source, 12 printable parts, and build notes: REPO_LINK
>
> Still a prototype. Here's a real run.

Replace `REPO_LINK` with the verified public URL. Attach an approved real clip;
do not use a simulator recording without labeling it.

## Clip outline

- Show the physical arm and the plain-language inspection request.
- Briefly show the preview, then the arm moving in the same continuous shot.
- Show the returned image and what it actually reveals.
- End on the repository name/link.

Keep one attempt understandable. If it needed a retry, show or disclose it.
Avoid speed, accuracy, autonomy, or reliability claims that were not measured.

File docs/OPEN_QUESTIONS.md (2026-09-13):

# Open owner questions

These are the few project details still waiting to be filled in.

## Public prototype decisions

- [x] Public source release authorized on 2026-09-13.
- [x] Attribute the project to its existing public creator, over-TT.
- [x] PolyForm Noncommercial 1.0.0 for software; CC BY-NC 4.0 for designs,
  documentation, and media. See `LICENSING.md`.
- [ ] Confirm whether future CAD/STLs are entirely original or derived from
  vendor/community files, and record every source.

The owner reports one Base bearing. Its exact specification and the complete
purchased-parts list can follow the prototype/demo release; the assembly guide
remains explicitly incomplete.

## Hardware identification

- [ ] Photograph the labels on all three main servos.
- [ ] Photograph the SC09 camera servo label.
- [ ] Photograph both sides and the printed revision of the servo HAT.
- [ ] Photograph the power-supply label.
- [ ] Photograph and confirm the Camera Module 3 Wide board/revision label.
- [x] Record the Base gear pair: 52-tooth printed ring and 13-tooth printed
  servo gear for 4:1 reduction.
- [x] Add the current 13-tooth Base-servo gear file.

## Reproducible mechanical build

- [x] Add and index all 12 current printed parts.
- [x] Name the lower/upper links and record the bearing-bottom placement.
- [ ] Send the large Base bearing details.
- [ ] Add the heat-set insert and M3 screw list.
- [ ] Add the remaining nuts, washers, spacers, shafts, horns, and cable ties.
- [ ] Record material, nozzle, layer height, wall count, infill, support, and
  orientation for every printed part.
- [ ] Record the actual arm mass and maximum intended payload.
- [ ] Add the remaining CAD, drawings, and exports when ready.

## Electrical and power

- [ ] Confirm connector types, wire gauges, polarity, and wiring colors.
- [ ] Confirm fuse or circuit-protection details.
- [ ] Confirm whether a dedicated physical emergency power cut is installed.
- [ ] Record the normal and worst observed supply current/voltage.
- [ ] Confirm how Pi power and servo-rail power are isolated to avoid backfeed.

## Media

- [ ] Take the overview, detail, assembly, wiring, label, and motion shots from
  the [media guide](MEDIA_GUIDE.md).
- [ ] Decide whether long video uses Git LFS, GitHub Releases, or external
  hosting. The default recommendation is short compressed clips in Releases
  and linked long-form video elsewhere.

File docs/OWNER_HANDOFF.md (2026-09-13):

# Owner handoff

This page is the practical drop-off list for completing the repository. The
folders already exist so files can be added without redesigning the tree.

## Where each file goes

| What you have | Put it here | Notes |
| --- | --- | --- |
| Editable/native CAD assembly and parts | `hardware/cad/native/` | Keep the main assembly and its external references together |
| Neutral CAD for reuse | `hardware/cad/step/` | Export STEP AP242 or AP214 in millimetres |
| Printable 3MF parts | `hardware/3mf/` | Use the clean part names already established there |
| Slicer-ready meshes | `hardware/stl/print-ready/` | One oriented binary STL per printable part, in millimetres |
| Dimensioned drawings | `hardware/drawings/` | PDF plus DXF when useful |
| Exact parts and quantities | `hardware/bom/bom.csv` | Replace TODO rows; do not invent supplier IDs |
| Electrical schematics | `hardware/electronics/schematics/` | Prefer editable source plus PDF/SVG export |
| Point-to-point wiring and harness drawings | `hardware/electronics/wiring/` | Include connector mating view, polarity, gauge, and labels |
| New unreviewed photos/videos | local `media/raw/` | Ignored by Git; never stage this folder |
| Approved whole-arm photos | `media/photos/overview/` | Remove metadata and personal background details |
| Approved build-step photos | `media/photos/assembly/` | Match filenames/captions to assembly steps |
| Approved label/detail photos | `media/photos/details/` | Blur serials/QR codes if they are not needed |
| Original diagrams | `media/diagrams/` | Prefer editable SVG plus PNG fallback |
| Small approved clips or video links | `media/video/` | Use Releases/external hosting for long video |

Read [`CAD_AND_STL.md`](CAD_AND_STL.md) before exporting geometry and
[`MEDIA_GUIDE.md`](MEDIA_GUIDE.md) before adding images.

## Minimum useful CAD package

All 12 current printed parts are now in `hardware/3mf/`. To finish the
mechanical package, add:

1. the editable assembly and part sources;
2. a full neutral STEP assembly;
3. individual STEP parts;
4. one print-ready STL per printed part;
5. dimensioned drawings for critical interfaces;
6. a revision-matched BOM;
7. material and print settings;
8. a short change note in `CHANGELOG.md`.

Use the same two-digit revision in every matching filename. Do not overwrite a
released revision with different geometry.

## Minimum useful photo package

Start with these twelve shots:

1. complete arm, front three-quarter;
2. complete arm, side;
3. complete arm, folded/rest pose;
4. Base gear and zero mark;
5. Base servo label;
6. Shoulder servo label;
7. Elbow servo label;
8. camera servo and camera-module labels;
9. HAT top;
10. HAT bottom/revision;
11. power-supply label and power-disconnect path;
12. full wiring/cable-routing overview with power off.

The raw originals stay outside Git. Only the reviewed exports enter the tracked
folders.

## Before staging new material

```powershell
python tools/check_repo.py
git status --short
```

Then inspect exactly what will be staged:

```powershell
git add <explicit-file-or-folder>
git diff --cached --stat
git diff --cached
```

Avoid using a broad add command when raw media or unrelated local files are
nearby. The repository check catches common release mistakes, but visual review
is still required.

## Owner decisions still required

The public prototype release and noncommercial license split are authorized;
see [`LICENSING.md`](../LICENSING.md). The remaining owner/build facts are in
[`OPEN_QUESTIONS.md`](OPEN_QUESTIONS.md). Detailed third-party provenance,
complete build reproduction, and approved demo media remain follow-up work.
The ARM-only software scope is recorded in `SOURCE_RELEASE_PLAN.md`.

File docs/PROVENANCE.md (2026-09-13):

# Provenance and privacy

## Source boundary

This clean repository is an allowlisted export from a larger private robotics
workspace. It deliberately excludes unrelated application code, generated
toolchains, build outputs, firmware backups, tokens, SSH material, service logs,
retained camera frames, screenshots, local caches, account state, and the raw
chronological agent handoff.

Generated engineering reports are also excluded until they can be regenerated
without personal paths and with fonts/assets whose redistribution terms are
understood. A PDF or screenshot is not made public merely because its
underlying source is public.

The public history was rebuilt from the current arm contract and dated proof
records. Installation-specific values were removed rather than replaced with
plausible-looking examples.

## Data never intended for this repository

- credentials, bearer tokens, private keys, or known-hosts files;
- personal absolute paths or usernames;
- fixed private-network addresses, host fingerprints, or service credentials;
- exact controller, USB, MAC, boot, plan, or camera-frame identifiers;
- raw desk-camera media or unreviewed screenshots;
- factory firmware backups or generated vendor binaries;
- account tier, model catalog, transcripts, or personal AI memory;
- logs containing command lines, paths, or network topology.

## Hardware and CAD provenance

Vendor and product names identify compatibility targets and remain the property
of their owners.

All 12 current 3MF parts were supplied directly by the project owner on
2026-08-26. Their archives contain model titles/revisions and geometry but no
author name, source URL, or third-party license metadata. On 2026-09-13 the
owner authorized their inclusion in the public prototype under the applicable
terms in [Licensing](../LICENSING.md). This records the owner's release decision,
not an independent audit of mesh authorship. The license grants only rights
the licensor can grant. Record the source, author, original license, changes,
and revision for any adapted material in `hardware/3mf/README.md`; third-party
rights and notices remain unchanged.

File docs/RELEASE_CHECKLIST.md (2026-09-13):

# Release checklist

## Owner decisions

- [x] Public prototype source release authorized on 2026-09-13.
- [x] Attribution: co-arm by over-TT.
- [x] PolyForm Noncommercial 1.0.0 for software; CC BY-NC 4.0 for designs,
  documentation, and media; see `LICENSING.md`.
- [x] ARM-only software-export scope recorded in `SOURCE_RELEASE_PLAN.md`.
- [ ] CAD and media provenance confirmed.
- [ ] Hero photo, dashboard screenshot, short proof clip, and social preview
  approved for public use.

## Documentation

Full build reproduction and approved demo media remain follow-up milestones;
they are not claimed by this public prototype source snapshot.

- [ ] No `TODO(owner)` needed for a claim presented as reproducible.
- [x] Status date and evidence tiers are current.
- [ ] BOM matches photographs and labels.
- [ ] Geometry matches the exported CAD revision.
- [x] All relative links pass.
- [x] Prototype and physical limitations remain documented.

## Privacy and secrets

- [x] No personal absolute paths or machine-account names found by the release checks.
- [x] No installation-specific IPs, host fingerprints, private-key names, or
  credential/token paths; any documented private subnet is an explicit
  portable default/example rather than reference-machine state.
- [x] No controller, MAC, USB serial, boot, or frame IDs from the reference
  installation.
- [x] No raw logs, camera frames, screenshots, caches, backups, or build trees.
- [ ] Media was reviewed and metadata removed.
- [x] `python tools/check_repo.py` passes.
- [x] `python tools/build_source_manifest.py --check` passes.

## Source release

- [x] Configuration is templated and secrets are environment/file inputs.
- [x] Dependencies and versions are documented.
- [x] Applicable license texts and package metadata are present; third-party notices are retained.
- [x] Python gateway/backend/MCP/simulator suites, dashboard tests/build, and
  applicable firmware host tests pass from the local release tree; see `STATUS.md`.
- [ ] The GitHub Source validation workflow passes for the exact pushed commit.
- [x] Generated binaries are excluded unless redistribution was reviewed.
- [x] Source/build evidence is not described as physical proof.

## Git and GitHub

- [ ] Review `git status --short` and `git diff --cached`.
- [ ] Stage only the clean `co-arm` repository.
- [ ] Confirm no file is unexpectedly large.
- [ ] Commit message describes the ARM source export.
- [ ] Push to the intended private/public repository.
- [ ] Review the rendered README and Mermaid diagram on GitHub.
- [ ] Add the GitHub description, homepage/demo link, and focused topics.
- [ ] Upload the reviewed social-preview image and create a tagged release.
- [ ] Configure GitHub private vulnerability reporting or publish a private
  security contact before inviting outside testing.
- [ ] Enable branch protection and secret scanning where available.

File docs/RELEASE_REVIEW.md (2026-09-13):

# Release review — engineering 2026-09-05; publication scope 2026-09-13

The first release should describe a working four-axis camera-arm prototype,
with source and printable parts. It is not yet a complete copy-and-build kit.
Do not publish the current recovery tools as a supported physical recovery path.

On 2026-09-13 the owner authorized publishing this prototype source with
PolyForm Noncommercial 1.0.0 software and CC BY-NC 4.0 designs/documentation/media.
The exact single-bearing specification, full parts schedule, and approved demo
are follow-up milestones. The outstanding device tests below remain required
before claiming supported recovery or exact-stack physical acceptance.

This review covered the exported gateway/backend, dashboard, MCP boundary,
simulator contracts, firmware host tests, installation, packaging, operations,
documentation, and release checks. It is a focused engineering review, not a
formal security certification or a new physical-arm acceptance test.

## Fixed in this candidate

- Live Follow recovers correctly from React StrictMode's development effect
  replay, which previously left it waiting permanently for telemetry. A
  lifecycle regression covers telemetry, start, and end. Physical Live behavior
  still needs a fresh test on the exact installed stack.
- Recovery now has a separate Base-reference gate, dashboard/MCP reporting,
  explicit zero confirmation, durable calibration readback, and final-dispatch
  checks. Disk failures and a gate appearing during hold cannot unlock motion.
- Fresh backups permit absent historical recovery metadata and record whether
  older provenance matches the frozen calibration. Portable Prepare verifies a
  protected archive and creates archive-bound provenance plus the Base gate;
  it does not assert physical continuity or silently trust an older hash.
- Camera arrival and goal pursuit now use the reviewed 6-degree / 17-tick
  tolerance. Base, Shoulder, and Elbow retain their 1-degree checks; the
  shutter-time pose-drift check also stays at 1 degree.
- The dashboard allows 9 seconds for a quiet Camera target to settle. It
  rejects invalid requested angles, ignores an unrequested nullable Base,
  and keeps the real destination when a partial floor route is returned.
- The gateway exposes a process-stable response identity. The backend checks
  restart identity across reviewed requests, rejects malformed negotiated
  identity, and keeps camera evidence bound to the response that produced it.
- The Python test extra declares NumPy and headless OpenCV for the simulator
  pixel/JPEG policy tests. A fresh environment previously failed collection.
- The source manifest now matches the LF bytes in a Git archive. The release
  checker rejects CRLF text so Windows line endings cannot silently make a
  locally passing manifest fail in a fresh checkout.
- The [quickstart](QUICKSTART.md) is separate from the full setup runbook.
  Reconnecting an existing arm no longer reads like a full rebuild.

See [Status](STATUS.md) for the exact verification results and their limits.

## Remaining acceptance and demo work

### 1. Recovery still needs device round-trip acceptance

The following source-level findings are addressed by local regressions. They
are not a claim that a replacement Pi has been restored successfully:

1. **Restored Base calibration can be paired with the wrong valid frame.**
   Bootstrap restores the archived `rawZero`. The gateway can adopt a HAT
   frame that remained valid while the Pi was replaced/restarted, but it does
   not bind that frame to the archived calibration. If the Base was re-zeroed
   after the snapshot and the HAT remains powered, clearing the generic STOP
   latch can expose mismatched calibration as trusted. A true cold HAT/servo
   continuity loss still blocks Base; this finding is not a claim that every
   restore immediately permits motion. The new independent gate hides Base
   truth and blocks motion until explicit re-zero and durable readback succeed.
2. **A verified archive may contain stale calibration provenance.** Normal
   calibration changes the calibration JSON without refreshing the older
   recovery-provenance hash. Backup can preserve both while restore rejects
   that pair. Prepare now derives fresh provenance from the verified archive's
   actual frozen calibration; any separately supplied pair must match exactly.
3. **Fresh installs lack required recovery metadata.** Backup requires files
   created by the restore workflow, not by ordinary initial deployment. The
   script also took separately prepared inputs rather than an archive. Old
   metadata is now optional; protected archive input is required for restore.

Relevant implementation: [restore script](../software/operations/scripts/restore-arm-pi.ps1),
[backup script](../software/operations/scripts/backup-arm-pi.ps1), and
[calibration/Base state](../software/python/robot_gateway/simple_arm_api.py).

Remaining device acceptance: exercise fresh deployment, calibration change, snapshot, archive
input conversion, dormant restore, retained-valid HAT frame, cold HAT frame,
explicit physical re-zero, and verified post-change snapshot. The restored
Base must remain untrusted until the new reference is confirmed. Include
tampered/stale provenance and failed-write cases. Do not fabricate metadata or
clear STOP to make a recovery check pass.

### 2. Public terms selected; media and detailed provenance remain

The owner selected the noncommercial license split and existing over-TT
attribution in [Licensing](../LICENSING.md). The owner-supplied printable parts
are included under that scope; third-party rights remain unchanged. Record
any adapted-material provenance and approve photos/clip before adding them.
No approved public photos or videos are included yet.

### 3. New builders still need physical facts

The 12 printable parts are present. A reproducible build still needs the
bearing specification, inserts and screw lengths/counts, shaft/horn details,
tested materials/print settings, and as-built wiring and power/protection
details. Use the [open questions](OPEN_QUESTIONS.md) and
[BOM](../hardware/bom/bom.csv); do not guess these from source code.

### 4. The exact released stack needs its own evidence

Local tests do not prove an installed Pi, flashed controller, running Isaac
scene, or physical arrival. Validate the exact candidate on the reference arm
with a bounded supervised commissioning/demo run. After an explicitly approved
push, check the GitHub workflow for that exact commit and inspect the rendered
documentation. The authorized public prototype snapshot does not claim that
the unfinished physical acceptance work passed; a release tag is a separate step.

## Recommended next scope

1. Complete the physical recovery round trip using the tested source candidate.
2. Make one inspection demo repeatable: request a viewpoint, preview, measured
   arrival, and a camera image that visibly answers the request. Record several
   attempts and report the actual successes/failures instead of a broad
   reliability percentage.
3. Capture a short real clip and one clean overview photo. Put the clip and
   a one-sentence description near the top of the README after approval.
4. Finish the missing assembly/BOM/wiring facts, then ask a new reader to follow
   the quickstart and build instructions without oral corrections.

The local disconnected dashboard opens correctly and keeps Control/Live
disabled. Its next useful usability improvement is an inline connection/setup
entry point in that empty state; users currently have to leave the interface
for the runbook. Keep new features out of this release until setup, recovery,
and one good demo are dependable.

## Publication boundary

The owner authorized the noncommercial licenses, Git push, and public
repository visibility on 2026-09-13. That authorization covers the documented
prototype source snapshot. It does not claim completed hardware acceptance,
approved demo media, a tagged release, or a social post. The
[launch draft](LAUNCH_DRAFT.md) remains a draft for the later demo.

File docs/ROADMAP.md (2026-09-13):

# Roadmap

## R0 — public documentation scaffold (complete)

- Complete the public-safe documentation scaffold.
- Established the ARM-only repository boundary and privacy checker.
- Run privacy, link, size, and required-file checks.
- Push the first private review commit.

## R1 — reproducible hardware package

- Added all 12 current printable parts and a concrete Base-to-camera assembly
  map.
- Recorded the printed 52:13 Base gears and 4:1 reduction.
- Named the lower and upper links and recorded the bearing-bottom position.
- Next: add the large bearing details, heat-set inserts, and M3 screw schedule.
- Add verified BOM and labeled hardware photographs.
- Add editable CAD, STEP, revision-matched STL, drawings, and print settings.
- Add a reviewed wiring diagram, power tree, fuse, and physical power-cut
  documentation.
- Record assembly and commissioning photographs.

## R2 — clean ARM software source export (source-complete; publication gates remain)

- Exported firmware, Pi gateway, MCP/plugin, simulator, operations helpers,
  ARM-only FastAPI backend, and standalone dashboard.
- Replaced installation-specific plugin/backend configuration with portable
  local inputs.
- Added locked dependency graphs, vulnerability gates, package resources,
  source-isolated wheel smoke, focused tests, clean-checkout CI, and Dependabot.
- Made the Codex tools identify SIM versus the real arm and read current state
  instead of blindly repeating a move whose reply was lost.
- Selected PolyForm Noncommercial 1.0.0 software and CC BY-NC 4.0
  designs/documentation/media for the authorized public prototype snapshot.
- Remaining work: check CI for the exact pushed commit, document adapted
  third-party material where applicable, and add approved demo media.

## R3 — final-path physical qualification

- Record numeric signed Base arrivals, seams, endpoints, repeated targets,
  mid-flight retargets, and re-home after continuity loss.
- Record a longer coordinated four-joint run.
- Measure physical floor clearance against the corrected model.
- Exercise plan/apply and record measured arrival.
- Characterize servo power, sag, temperature, and current behavior.

## R4 — repeatable active-vision demo

- Add one clean three-quarter hero photograph and one dashboard plan-preview
  screenshot.
- Record a 10-20 second `state -> preview -> move -> joint readback -> camera
  result` clip.
- Capture a proven wide survey, retained-source crop, and centered close pass.
- Define image-based success criteria for framing and visible detail.
- Rehearse repeatable object localization without claiming exact identity until
  close evidence supports it.
- Add a reviewed social-preview image, then publish the media with raw/private
  originals kept out of Git history.

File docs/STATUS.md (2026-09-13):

# Status and evidence

Last engineering review: **2026-09-05**. License/publication update: **2026-09-13**.

The owner selected PolyForm Noncommercial 1.0.0 for software and CC BY-NC 4.0
for designs, documentation, and media, and authorized a public prototype
source release. See [Licensing](../LICENSING.md). The single Base bearing's
specification, full purchased-parts list, and approved demo media remain
follow-up work. This scope does not claim a complete reproducible build kit.

## September 13 public prototype validation

The final local release tree passed **848 Python tests plus 9 subtests**,
**201 dashboard tests**, **17 Arm HAT host tests**, TypeScript and the 42-module
Vite production build, and parsing of all **6 operations scripts**. The Python
wheel built successfully, its PolyForm license expression and bundled
license/notice matched the source, and its separate installed-environment
smoke passed. Existing release test environments were reused; this was not a
new dependency installation or a new dependency-vulnerability audit.

The **161-file software manifest**, **241-file repository check**, and Git
whitespace check passed. The only repository warning is the absent approved
demo media. A scan of all existing Git refs covered **365 distinct file
revisions** without a private-data-pattern, forbidden-file, or oversize finding.

Windows recovery fixtures need a short temporary path: the deeply nested
checkout path exceeded a filesystem path limit in the first full attempt.
The complete run passed from a short temporary directory. Starlette
deprecations and the known jsdom canvas notice remain non-failing warnings.

This validation does not constitute a Pi deployment, firmware flash, new
physical trial, or completed recovery round trip. The exact pushed commit's
GitHub workflow and visibility are verified separately from local results.

This page reports evidence, not aspiration. Historical hardware statements are
dated. Nothing in the repository is fresh live state.

Release assessment: a source/reference-build candidate, not a complete
copy-and-build kit. Recovery's software guards are now covered locally, but a
replacement-device round trip and fresh physical Live acceptance are still
required; see [Release review](RELEASE_REVIEW.md).

## September 5 follow-up: Live and recovery

- Fixed Live remaining stuck after React StrictMode effect replay. The new
  regression exercises telemetry, explicit startup, and session end.
- Restored Base calibration stays visibly untrusted even with a surviving HAT
  frame. Recovery disables Hold/drive/Live, survives Clear STOP, and requires
  explicit measured zero plus durable readback. Release and STOP remain usable.
- Final grouped/legacy dispatch rechecks the recovery gate after hold
  acquisition; failure-path tests cover mid-command gating and persistence.
- Backup permits absent historical restore metadata and describes stale
  provenance without rewriting it. Portable Prepare verifies an archive and
  produces new archive-bound provenance and the independent Base marker.
- The setup runbook now documents archive preparation and the distinction
  between pre-commissioning Verify and a new post-zero protected snapshot.
- CI includes actual Windows recovery regressions, not only script parsing.
  This workflow change has not been pushed or run on GitHub.

Final local verification on Windows (Python 3.11.9 / Node 24.14.1), reusing
the existing test environments:

- **848 Python tests and 9 nested subtests passed** across the gateway, backend,
  MCP, simulator contracts, operations, and source-index tests.
- **201 dashboard tests passed**, followed by TypeScript and the 42-module
  Vite production build.
- A new isolated PEP 517 wheel build succeeded. All **44 payload files** match
  the final source manifest; source-isolated imports loaded the four package
  entry modules from its separate installed target directory.
- All **6 PowerShell operations scripts parsed**. Recovery tests include real
  GNU-tar layout fixtures, owner-only Windows permissions, read-only Verify,
  changed-input refusals, durable Base-gate ordering, and activation contracts.
- The **159-file software manifest** and **236-file repository check** pass.
  Only the unchosen license and absent approved media warnings remain.

Starlette deprecations, jsdom's missing-canvas notice, and cleanup permissions
on an older Windows temporary fixture remain visible; they did not fail tests.
Dependency audits, firmware host tests, and the full fresh-environment smoke
below are September 4 evidence, not newly repeated claims.

These are local software changes. No Pi deployment, service restart, firmware
flash, physical motion, or remote mutation was performed. A read-only state
check found the reference arm online, but that is not a physical Live test.

## September 4 release baseline (historical verification)

| Area | Included state | Evidence tier |
| --- | --- | --- |
| Dashboard | Standalone React/Vite Overview, guarded Control, bounded Live Follow, camera/calibration controls, Guide, Control Center, and SIM/REAL selection | Fresh locked install; 197 tests; 42-module production build; dependency audit; disconnected browser smoke |
| Local backend | Loopback-only FastAPI runtime, browser session boundary, Control Center, explicit SIM/REAL routing, and response-bound process identity | Source inspection; included in the 769-test Python run and installed-wheel smoke |
| Pi gateway | Four-joint state/calibration, floor guard, plan/apply/sequence, Live Follow, camera evidence, commissioning, Camera arrival tuning, and process-stable response identity | Source inspection; included in the 769-test Python run; no deployment in this review |
| Arm MCP/plugin | Typed Arm tools, explicit SIM/REAL identity verification, structured MCP output, repo-local marketplace, setup skill, and configured-arm runtime skill | MCP/index tests included in the full Python run; plugin/marketplace and both skills validated; no installed configuration changed |
| Isaac Sim | Four-joint URDF/model, deterministic desk/camera scene, bounded interpolation and frame-quality policy, persistent bridge, simulator HTTP gateway, and supervised launcher | Source/contracts tested; effective square-pixel Camera Module 3 Wide projection is explicit; Isaac runtime and vendor assets are not bundled |
| Arm HAT | `arm-hat-2.7.2` ESP32 controller source, shared library, and protocol fixtures | 17 host tests passed; device build/flash remains a separate tier |
| Operations | Pi service templates, deployment, physical-UART mode control, status, backup/restore/imaging, firmware compile helper, and Isaac launcher | Six scripts parsed; source/contracts tested; recovery findings at this baseline motivated the September 5 follow-up |
| Printable parts | All 12 current printed parts: both Base gears, the Base stack, arm links, servo mounts/covers, and camera holder/cover | Files inspected; final print settings are not included |

The preceding baseline verification completed on 2026-09-04 using Windows, Python
3.11.9, Node 24.14.1, and pnpm 11.19.0. Python used a new virtual environment;
dashboard dependencies were installed from the frozen lock in a separate copy
of the candidate source, without replacing an existing installation:

- gateway, backend, MCP, Isaac contract, deployment/recovery, and source tests:
  **769 passed, plus 9 nested subtests**; four Starlette deprecation warnings
  remain visible. Pytest also reported a Windows permission warning while
  cleaning an older temporary fixture; it did not fail a test;
- dashboard: **197 passed**, followed by a successful TypeScript/Vite
  production build with 42 modules transformed. jsdom reported its known
  missing-canvas implementation during an accessibility test;
- an isolated PEP 517 build produced and cleanly installed the
  `co_arm_stack-0.1.0-py3-none-any.whl` artifact; `pip check` and a
  source-isolated smoke loaded the packaged simulator URDF/JSON, confirmed test
  suites were excluded, proved package imports came from the isolated wheel
  environment, and confirmed that the dashboard CLI exits honestly
  when the separately built frontend assets are absent;
- all **44 wheel payload files** matched the release source manifest by SHA-256;
- no-gateway browser smoke: the built Overview and Guide loaded, no backend
  was configured, and Control/Live stayed disabled. A separate loopback test
  server was used; no real-arm service or simulator was started;
- Arm HAT host/protocol suite: **17 passed**;
- all **6** retained PowerShell operations scripts parsed without syntax
  errors;
- the `co-arm` plugin manifest and marketplace validated, and both setup and
  runtime skills passed their skill validators;
- the exact Python lock, Raspberry Pi requirements, and dashboard dependency
  graph returned no known vulnerabilities from their audit services;
- the source manifest is current across **155 software files**, and the
  repository checker reviewed **232 files** with only the documented missing
  license and approved-media warnings. The earlier missing-CAD warning is gone
  because all 12 current 3MF files are included.

The fresh Python run first failed collection because NumPy/OpenCV were absent
from the declared test dependencies. The test extra and regenerated lock now
include them; the complete suite above passed after the correction. This is
why an earlier already-populated interpreter is not clean-install evidence.

A Git-archive check also exposed 20 stale manifest hashes caused by Windows
CRLF bytes being converted to LF on commit. Source text was normalized to the
repository's declared LF format and an LF release gate with two regressions
was added. The final committed archive must pass the same manifest and
repository checks as the working tree before publication.

The checked-in GitHub workflow now repeats the source, test, build, package,
PowerShell, and dependency-audit gates, and Dependabot covers Python, Raspberry
Pi requirements, pnpm, and GitHub Actions. A GitHub-hosted run still requires
the exact candidate to be pushed; local inspection does not prove that remote
run.

The deterministic manifest and repository checker are the final tree-level
gate after any edit. These checks prove only the exported source and local build
environment; they do not prove a deployed service, Isaac runtime, flashed
controller, or physical arm. Re-run them for the exact commit being published.

## Agent-guided setup boundary

`AGENTS.md`, `docs/SETUP_WITH_CODEX.md`, `software/SOURCE_INDEX.json`, and the
repo-local setup skill give an agent an ordered path through checkout validation,
dashboard startup, Isaac setup, blank-Pi prerequisites, gateway deployment,
firmware compilation, tunnel/MCP configuration, commissioning, and operation.

That path covers source validation and connection to an existing commissioned
arm. A supplied Isaac installation still needs its own runtime verification.
The portable physical recovery branch still needs replacement-device
acceptance and must not be treated as a proven SD-card recovery kit. A reproducible new mechanical
build is now partly documented by all 12 printable parts. It still needs the
bearing details, full fastener and print schedule, as-built wiring/pinout, and
power details before it becomes a complete copy-and-build package.

## Current reference-build contract

| Area | Reference state | Evidence boundary |
| --- | --- | --- |
| Mechanism | Four driven joints: Base, Shoulder, Elbow, Camera | Source plus earlier physical observation |
| Geometry | 60 mm pivot, 180 mm upper arm, 220 mm elbow-to-tip | Configured/measured reference values, not manufacturing tolerances |
| Gateway | Raspberry Pi 4, Camera Module 3 Wide / IMX708, ESP32 Arm HAT | Source plus dated deployed evidence |
| Base | ST3215/STS plus 3D-printed 52:13 gear pair for 4:1 reduction; native Mode-0 signed absolute goals | Owner-supplied Base 3MF metadata plus earlier register readback and physical motion acceptance |
| Shoulder / Elbow | ST3215/STS-family path; grouped bounded Live Follow available | Source plus dated unloaded physical runs |
| Camera joint | SC09/SCS-family path, excluded from endpoint IK | Source tests plus earlier bus/motion observations |
| Vision | 2304 x 1296 survey and 4608 x 2592 detail profiles | Source plus dated deployed capture/status evidence |

## Previously recorded reference-arm evidence

These facts were recorded on the private reference system before this public
export. They are historical device evidence, not live verification made from
this checkout:

- The Pi, Camera Module 3 Wide, Arm HAT, and four servo IDs operated together.
- Native Base extended-position configuration and signed motion were read back
  and physically exercised after the earlier Mode-3 path was retired.
- Camera Module 3 Wide reported the IMX708 sensor/array and delivered upright
  survey/detail captures with powered autofocus controls. Focus still requires
  same-capture AF metadata plus visible subject detail.
- On 2026-08-23, matching Arm HAT `2.7.2`, Pi, and dashboard code completed
  unloaded Shoulder/Elbow Live Follow runs at raw speed `2400`, acceleration
  `50`, and a `±90 deg` start-relative allowance for five and twelve seconds.
- The twelve-second run recorded 223 accepted input frames, 52 verified grouped
  dispatches, 89 heartbeats, and an orderly client release.

That Live Follow evidence proves only the tested unloaded path. Raw speed is not
degrees per second, acceleration `50` is the installed-servo policy limit, and
the run does not establish every pose, load, overshoot, collision, cable, power,
or thermal condition.

## Still requiring live/device/operator proof

- An installed Isaac Python launcher, compatible GPU/driver stack, and a passing
  bridge/camera self-test; Isaac was not launched during this source review.
- Arduino CLI/ESP32-core compilation, upload, readback, and installed firmware
  identity; Arduino CLI was unavailable during this review.
- Pi deployment, service restart/hold behavior, loopback tunnel, camera, UART,
  controller, bus, and servo state on the target machine.
- Fresh STOP, torque, Base-continuity, calibration, telemetry, measured arrival,
  floor-clearance, cable/obstacle, power-sag, current, thermal, and stall checks.
- Remaining CAD and drawings; bearing details; fasteners; materials and print
  settings; as-built wiring/pinout; power details; and reviewed public media.

## Distribution boundary

The category-specific noncommercial terms are in [Licensing](../LICENSING.md). Runtime
state, captures, private reports, credentials, backups, toolchains, installed
agent configuration, and unrelated workspace code are intentionally absent.
The dashboard contains no embedded agent runtime; agent operation uses the
external MCP server/plugin with machine-local configuration.

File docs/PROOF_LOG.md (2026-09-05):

# Proof log

This compact log records the strongest public-safe evidence. It omits private
paths, device serials, network details, opaque frame IDs, credentials context,
and raw personal workspace history.

| Date | Claim | Evidence | What it does not prove |
| --- | --- | --- | --- |
| 2026-08-05 | ST3215 load-decode defect identified and fixed | Firmware analysis, tests, later hardware behavior | Final Base reliability |
| 2026-08-05 | SC09 ID collision isolated and camera servo assigned ID 4 | Isolation and clean four-ID scan | Long-duration bus reliability |
| 2026-08-07 | Earlier Mode-3 control moved all joints and reached wide Base angles | Live motion observations | Reliability of the later 2.4 control path |
| 2026-08-08 | Codex used typed tools to move and capture a real image | Live telemetry and pixels | General autonomous perception |
| 2026-08-08 | Earlier Base bookkeeping could report false zero | Controlled failure observation | A defect in the later native Mode-0 method |
| 2026-08-10 | Native extended-position configuration persisted | Physical register readback before and after power cycle | Numeric arrival across all travel |
| 2026-08-10 | Normal Base signed motion and return accepted | Operator physical observation | Seam, endpoint, retarget, or endurance table |
| 2026-08-11 | Full-resolution fixed-focus capture deployed | Live capture plus metadata | Autofocus or exact object identification |
| 2026-08-11 | Plan/apply preview deployed | Live motionless preview, zero warnings | Physical plan application or arrival |
| 2026-08-12 | Link and bus online; floor guard on; Base angle unavailable | Read-only live state | Complete current pose or Base truth |
| 2026-08-22 | Camera Module 3 Wide path reported IMX708 identity/array, upright capture, and powered AF controls | Deployed status/capture evidence | Wide lens variant from sensor ID alone, or sharpness from a control request alone |
| 2026-08-23 | Five- and twelve-second unloaded Shoulder/Elbow Live Follow runs completed at raw 2400/50 with a ±90 deg allowance | Matching deployed 2.7.2 stack, grouped goal readback, measured trace, heartbeat, orderly release | Degrees/second, every load/pose, collision sensing, or long-duration reliability |
| 2026-08-24 | ARM-only dashboard/backend, gateway, firmware, simulator, MCP/plugin, operations, and tests exported | Public source inspection and clean-checkout verification workflow | Deployment, current live state, or new physical behavior |
| 2026-08-25 | Focused four-joint arm/Pi/Arm HAT/Isaac/dashboard/agent source boundary validated | 689 Python tests, 180 dashboard tests plus build, isolated Python wheel-artifact build, no-gateway dashboard runtime smoke, 17 Arm HAT host tests, six parsed PowerShell scripts, current 147-file manifest, and 207-file repository check | A self-contained wheel runtime, Isaac launch, Arduino device build/flash, Pi deployment, or physical-arm proof |
| 2026-08-26 | Agent contract and local release candidate hardened | 714 Python tests plus 9 nested subtests, 49 focused MCP/index tests, 180 dashboard tests plus 42-module build, clean Python/Pi/dashboard dependency audits, source-isolated installed-wheel smoke, 17 Arm HAT host tests, six parsed PowerShell scripts, validated plugin and skills, current 151-file manifest, and 212-file repository check | A GitHub-hosted workflow run, Isaac launch, Arduino device build/flash, Pi deployment, fresh live state, or new physical-arm proof |
| 2026-08-26 | Current printable mechanical set added | 12 3MF files inspected and indexed, including both Base gears; 225-file repository check passed | Print settings, fit on the physical arm, bearing details, or a complete fastener schedule |
| 2026-09-04 | Camera/restart fixes and fresh-install release review completed | 769 Python tests plus 9 nested subtests, 197 dashboard tests and 42-module build, isolated installed-wheel smoke, 44 manifest-matched wheel payloads, disconnected browser smoke, 17 firmware host tests, six parsed scripts, plugin/skill checks, clean dependency audits, current 155-file manifest, and 232-file repository check | Physical recovery readiness, GitHub-hosted CI, deployment, Isaac runtime, device firmware build/flash, or fresh physical-arm proof |
| 2026-09-05 | Live startup lifecycle and portable recovery hardened | 848 Python tests plus 9 subtests, 201 dashboard tests and 42-module build, new isolated wheel build and source-isolated package imports, 44 manifest-matched payloads, six parsed scripts, GNU-tar/Windows recovery regressions, current 159-file manifest and 236-file repository check | Physical Live responsiveness, replacement-Pi recovery, fresh dependency audits or firmware tests, deployment, or GitHub-hosted CI |

See [Status](STATUS.md) for the current proof matrix and [History](HISTORY.md)
for the engineering narrative.

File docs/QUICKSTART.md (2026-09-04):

# Open the dashboard

This gets the standalone co-arm dashboard running on your computer. You can
explore the interface without a Raspberry Pi, servos, camera, Codex, or Isaac
Sim. Movement and camera controls become available after a gateway is connected.

## 1. Install the prerequisites

These commands use Windows PowerShell. Install Git, Python **3.11**, Node.js
**20.19.x or 22.12+**, and **pnpm 11.19.0**, then check:

```powershell
git --version
python --version
node --version
pnpm --version
```

The Python lock was validated on 3.11. Node 21 and Node 22.0–22.11 are outside
the dashboard's supported range. The pnpm version is pinned in
[`package.json`](../software/dashboard/package.json).

## 2. Get and build the software

If you already have the checkout, open PowerShell in its root and skip the
first two lines. Run each stage only after the preceding command succeeds.

```powershell
git clone https://github.com/over-TT/co-arm.git
Set-Location co-arm

python -m venv .venv
.\.venv\Scripts\python.exe -m pip install --upgrade pip
.\.venv\Scripts\python.exe -m pip install --requirement .\software\python\requirements.lock
.\.venv\Scripts\python.exe -m pip install --no-deps --editable .\software\python

pnpm --dir .\software\dashboard install --frozen-lockfile
pnpm --dir .\software\dashboard build
```

This creates a local Python environment and downloads the locked dependencies.
The frontend build goes in `software/dashboard/dist/`. Keep both in this
checkout; the Python package alone does not contain the built dashboard.

## 3. Open it

From the repository root:

```powershell
.\.venv\Scripts\python.exe -m web_backend
```

Open [http://127.0.0.1:8765/](http://127.0.0.1:8765/) and keep the terminal
running. The interface should load with no arm backend configured. Missing
joint readings, an unavailable camera, and unavailable movement controls are
expected at this stage. The Control Center can still offer local setup actions.

Press **Ctrl+C** in that terminal to stop this dashboard. To open it again,
repeat only the launch command. If port 8765 is already occupied, use
`--port 8766` and open `http://127.0.0.1:8766/`.

## Choose the next step

| You want to… | Continue here |
| --- | --- |
| Check the code and builds | [Source validation](SETUP_WITH_CODEX.md#1-clone-and-validate-without-hardware) |
| Move a simulated arm | [Isaac Sim setup](SETUP_WITH_CODEX.md#3-run-the-isaac-sim-arm); requires a separate Isaac installation |
| Connect an already commissioned arm | [Existing-arm path](SETUP_WITH_CODEX.md#existing-arm-short-path) |
| Build a new arm | [Assembly](ASSEMBLY.md), then [commissioning](COMMISSIONING.md); some physical build details remain unfinished |
| Let Codex use a connected arm | [External MCP setup](SETUP_WITH_CODEX.md#9-configure-the-external-mcp-agent) |

Opening the dashboard verifies the local interface. Simulator operation and
real-arm operation each need their own checks; see [status and evidence](STATUS.md).

## If it does not start

- **“No module named web_backend”:** use this checkout's `.venv` interpreter
  and repeat the editable-package install in step 2.
- **Missing dashboard assets:** run the dashboard build in step 2. A Python
  wheel installed elsewhere needs `--static-directory` pointing to that build's
  `dist` directory.
- **Dependency or build error:** confirm the prerequisite versions first and
  keep the lockfiles unchanged. Use the first failed command's error as the
  starting point.

The longer [setup runbook](SETUP_WITH_CODEX.md) covers source validation,
simulation, Pi deployment, hardware commissioning, and agent configuration.

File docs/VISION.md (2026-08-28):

# Vision and active perception

The end camera is an evidence sensor for observation and framing. It is not a
collision sensor, safety-rated device, or substitute for live joint telemetry.

## Reference camera behavior

The current reference build uses Raspberry Pi Camera Module 3 Wide. Its IMX708
sensor exposes a 4608 x 2592 native array and powered autofocus. The bounded
capture profiles use 2304 x 1296 for routine `survey` evidence and 4608 x 2592
for `detail`. Survey prefers continuous normal/full-range focus; detail may
request macro focus. The camera is physically mounted upside down, and the Pi
applies one 180-degree transform so newly delivered images are upright.

The gateway checks the driver-reported sensor and array against the explicitly
selected Wide profile; IMX708 alone cannot prove the lens variant. A focus
control request does not prove the subject became sharp. Use the same capture's
AF state/lens metadata together with visible fine detail in the subject region.
The older OV5647 path remains a fixed-focus compatibility profile, not the
current reference camera.

The simulator is deliberately separate from that physical-lens contract. Its
2304 x 1296 square-pixel pinhole model fits the nominal 102 degree horizontal
axis and therefore has a 69.57 degree effective vertical axis, not the physical
lens's nominal 67 degrees. SIM projection metadata exposes that effective FOV
and its fit axis. On REAL, the nominal 102 x 67 degree values are framing hints,
not calibrated pixel-to-desk geometry.

## Camera ray convention

- Camera servo `0 deg` points along the forearm.
- Positive Camera rotates the view downward.
- Negative Camera rotates the view upward.
- In the side-view model:

```text
forearm_absolute = (shoulder_servo + 90) + (elbow_servo - 90)
camera_ray       = forearm_absolute - camera_servo
```

Base centers the view horizontally around the desk. Shoulder and Elbow choose
height and standoff. Camera tilt changes vertical framing without changing the
kinematic endpoint.

## Three kinds of visual evidence

| Interface | Evidence | Important limitation |
| --- | --- | --- |
| `arm_scene` | Calculated side-view joints, tip, floor, and optical ray from measured angles | Not real pixels; does not show obstacles or framing |
| `arm_look` survey/detail | A newly captured upright JPEG plus near-capture pose and metadata | Proves only what is visible in that frame |
| `arm_detail` | A bounded crop from a retained full-resolution capture | No movement and no new photograph |

Use `deskProjection` numerically only when its `status` starts with
`available_`. In particular, `unavailable_uncalibrated` on REAL means the
camera intrinsics, lens distortion, mount extrinsics, or desk registration are
not sufficient to convert normalized pixels into desk millimetres or Base
bearing.

Capture retention is bounded. Treat the source token as ephemeral runtime data,
not a durable public identifier.

## Default active-perception loop

### 1. Establish live geometry

Read `arm_state`, then `arm_scene`. Do not use a remembered viewpoint as the
current pose. Confirm controller/bus health, trusted measured angles for every
needed joint, STOP clear, floor guard enabled, and a clear planned sweep.

### 2. Make a deliberate wide survey

Prepare an elevated, retracted, downward-looking whole-desk view with **Base
exactly `0 deg`**. Derive Shoulder, Elbow, and Camera from the current measured
scene and the assembled arm's verified calibration. Review the solid measured
arm, dashed proposal, exact angles, warnings, and swept clearance; then apply
the one-use plan.

Settle and verify measured arrival. Capture `arm_look(view='survey')`.

Arrival at the intended pose is necessary but not sufficient. The actual
pixels must visibly cover the useful desk area. If they do not, calculate one
bounded coordinated correction from the live scene and image error, plan/apply
it, and capture another survey before localizing.

### 3. Localize without another photograph

Use `arm_detail` on the successful survey's retained full-resolution source.
This is a digital crop: it makes no movement and takes no second picture. Use it
to select a candidate region and estimate how Base, standoff, height, and camera
tilt should change.

### 4. Make a centered physical close pass

Center primarily with Base. Use Shoulder/Elbow for height and distance, and
Camera for vertical aim. Preview the coordinated sweep, apply it, settle, read
measured state, and take a new capture. Use another retained-source crop before
requesting a full-resolution complete frame.

### 5. Rank useful detail

Judge focus first from the subject region:

- fine edges;
- readable silkscreen or labels;
- connector shapes;
- chip markings;
- distinctive layout.

`FocusFoM`, when present, is a relative same-frame libcamera metric. Compare it
only for the same subject at similar framing. A whole-frame score can rise
because the background is sharp while the target is not. Visible subject detail
outranks the score. For the current autofocus camera, require a settled AF
state/lens position from the same frame; for the legacy fixed-focus profile,
change standoff when a closer sample is visibly softer.

### 6. Repeat while evidence improves

There is no arbitrary fixed count of moves, captures, minutes, or iterations.
Continue bounded, reviewed viewpoints while they materially improve evidence.
Stop when the request is answered, useful progress is exhausted, a concrete
blocker appears, or the operator says stop.

## Identification standard

A wide survey can support a location or family-level candidate. It is not
enough for an exact model. Exact identification requires discriminating
close-frame evidence such as readable text, characteristic ports, chip labels,
or a unique board layout. If those cues are absent or soft, report uncertainty
and the next view that would resolve it.

## Named viewpoints

A named viewpoint is a calibration-scoped **destination**, never live state.
Store it only after:

1. measured arrival was verified;
2. pixels proved the intended coverage;
3. the camera/bracket and joint calibration revision were recorded;
4. the operator asked to retain it or confirmed it as useful.

Invalidate/reverify it after camera mount, bracket, link geometry, zero, limit,
or calibration changes. Device-specific viewpoint angles and proof-frame
identifiers belong in local calibration records, not the public generic guide.
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

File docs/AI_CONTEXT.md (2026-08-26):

# Public AI context

This is the short project context for an agent working on co-arm. It contains
stable build facts, not the arm's current pose or a replacement for reading the
real joints and camera.

## First-read order

For setup, Raspberry Pi connection, assembly, or commissioning, begin with
[`SETUP_WITH_CODEX.md`](SETUP_WITH_CODEX.md). It defines the shared human/AI
checklist, the ARM-only source boundary, and the allowed read-only Pi discovery
steps.

An agent should read, in order:
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

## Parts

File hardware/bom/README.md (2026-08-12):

# Bill of materials

[`bom.csv`](bom.csv) is the machine-readable as-built bill of materials. It is
seeded with the currently known electronics and intentionally incomplete
mechanical rows.

## Columns

| Column | Meaning |
| --- | --- |
| `item_id` | Stable public identifier such as `ACT-001`; never reuse an ID for a different part |
| `subsystem` | Functional group: compute, control, actuation, vision, power, mechanical, wiring, or hardware |
| `description` | Plain-language part description |
| `manufacturer` | Marked manufacturer; blank until confirmed |
| `manufacturer_part_number` | Exact model/MPN from label or datasheet |
| `supplier` | Supplier used for this build; blank if unknown |
| `supplier_sku` | Supplier catalog/SKU, not an order/account number |
| `quantity` | Quantity installed in one arm |
| `unit` | Usually `each`, plus `m`, `g`, or another explicit unit when needed |
| `revision` | Hardware/design revision where applicable |
| `status` | `recorded`, `owner-verification`, or `TODO` |
| `source_or_evidence` | Public-safe evidence note, drawing, photo, or official product reference |
| `notes` | Fit, variant, joint mapping, or unresolved question |

## Rules

- Transcribe exact labels; do not silently turn a working software profile into
  a confirmed manufacturer part number.
- Use one row per distinct part/specification. Split variants even when they
  have the same function.
- Do not store prices, personal order IDs, addresses, credentials, or private
  serial numbers.
- Add every printed part, bearing, shaft, gear, horn, fastener, insert, washer,
  spacer, connector, wire type, regulator, fuse, and mounting item before
  calling the BOM complete.
- Keep BOM revision references aligned with CAD and drawings.
- A blank field means unknown; `TODO` in `status` means the row itself is only a
  placeholder.

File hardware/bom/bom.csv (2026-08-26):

item_id | subsystem | description | manufacturer | manufacturer_part_number | supplier | supplier_sku | quantity | unit | revision | status | source_or_evidence | notes
COMPUTE-001 | compute | Raspberry Pi 4 single-board computer | Raspberry Pi | Raspberry Pi 4 |  |  | 1 | each |  | owner-verification | Recorded hardware identity | RAM capacity and board revision need label or system verification
CONTROL-001 | control | Bus Servo Driver HAT (A) with integrated ESP32 | Waveshare | Bus Servo Driver HAT (A) | Waveshare | 27577 | 1 | each |  | recorded | Recorded product name and SKU | Photograph front and back board labels and record board revision
ACT-001 | actuation | Serial-bus servo for Base Shoulder and Elbow | Waveshare | ST3215 / STS-family |  |  | 3 | each |  | owner-verification | Current working identification | Exact printed model suffix and voltage label must be checked; logical IDs 1 2 3
ACT-002 | actuation | Serial-bus camera pitch servo |  | SC09 / SCS-family |  |  | 1 | each |  | owner-verification | Current working identification | Exact manufacturer model and voltage label must be checked; logical ID 4
VISION-001 | vision | Raspberry Pi Camera Module 3 Wide with IMX708 sensor | Raspberry Pi | Camera Module 3 Wide |  |  | 1 | each |  | owner-verification | Current software and dated deployed sensor evidence | Photograph module markings and verify Wide lens variant; IMX708 identity alone is insufficient
POWER-001 | power | Candidate servo-rail DC power supply |  | 12 V 7.5 A 90 W candidate |  |  | 1 | each |  | owner-verification | Candidate rating only | Exact model input output connector polarity cable and measured margin are not confirmed
POWER-002 | power | Camera-servo regulator or step-down converter |  |  |  |  | 1 | each |  | TODO | Not yet documented | Confirm whether fitted and record input output setting current capability and thermal margin
SAFE-001 | power | Servo-rail fuse or over-current protection |  |  |  |  | 1 | each |  | TODO | Not yet documented | Record type rating location and protected conductor
SAFE-002 | power | Hardware emergency stop or latched power disconnect |  |  |  |  | 1 | each |  | TODO | Not yet documented | Software STOP is not a hardware E-stop
MECH-001 | mechanical | 3D-printed Base 4 to 1 gear reduction |  |  |  |  | 1 | set | r01 | recorded | Current Base and servo-gear files | 52-tooth Base gear and 13-tooth servo gear
PRINT-001 | mechanical | Printed Base with integrated 52-tooth ring gear |  |  |  |  | 1 | each | r01 | recorded | co-arm_base_main-body_r01.3mf | Material and print profile TODO
PRINT-012 | mechanical | Printed Base servo gear |  |  |  |  | 1 | each | r01 | recorded | co-arm_base_servo-gear_r01.3mf | 13-tooth gear for the Base servo
PRINT-002 | mechanical | Printed Base bearing-bottom piece |  |  |  |  | 1 | each | r01 | recorded | co-arm_base_bearing-bottom_r01.3mf | Sits underneath the large Base bearing
PRINT-003 | mechanical | Printed Shaft Base |  |  |  |  | 1 | each | r01 | recorded | co-arm_base_shaft-base_r01.3mf | Sits on top of the large Base bearing
PRINT-004 | mechanical | Printed Level 2 platform |  |  |  |  | 1 | each | r01 | recorded | co-arm_base_level-2-platform_r01.3mf | Attaches above Shaft Base after lower-servo preassembly
PRINT-005 | mechanical | Printed lower-arm servo mount |  |  |  |  | 1 | each | r01 | recorded | co-arm_shoulder_servo-mount_r01.3mf | Exact face screw direction and cable exit need a photo
PRINT-006 | mechanical | Printed lower arm link |  |  |  |  | 1 | each | r01 | recorded | co-arm_shoulder_lower-link_r01.3mf | Lower link
PRINT-007 | mechanical | Printed upper arm link |  |  |  |  | 1 | each | r01 | recorded | co-arm_elbow_upper-link_r01.3mf | Upper link
PRINT-008 | mechanical | Printed top-servo cover |  |  |  |  | 1 | each | r01 | recorded | co-arm_elbow_servo-cover_r01.3mf | Exact attachment screws and orientation need a photo
PRINT-009 | mechanical | Printed camera-servo mount |  |  |  |  | 1 | each | r01 | recorded | co-arm_camera_servo-mount_r01.3mf | Mounts at the end of the arm
PRINT-010 | mechanical | Printed camera holder |  |  |  |  | 1 | each | r01 | recorded | co-arm_camera_holder_r01.3mf | Holds Camera Module 3 Wide
PRINT-011 | mechanical | Printed camera cover |  |  |  |  | 1 | each | r01 | recorded | co-arm_camera_cover_r01.3mf | Closes the camera holder
BEARING-001 | hardware | Large Base bearing |  |  |  |  | 1 | each |  | owner-verification | Owner reports one large bearing | Inside diameter outside diameter width and bearing type pending
INSERT-001 | hardware | Heat-set inserts for roughly 4 mm modeled holes |  |  |  |  | each |  |  | TODO | Owner reports multiple heat-set insert holes | Thread outside diameter length and count per printed part pending
FASTENER-001 | hardware | M3 screws |  |  |  |  | each |  |  | TODO | Owner reports multiple M3 screws | Length head type and count per connection pending
HARDWARE-001 | hardware | Washers nuts spacers shafts servo horns and cable hardware |  |  |  |  | 1 | set |  | TODO | Awaiting physical inventory | Split into exact size material quantity and matching drawing references
WIRING-001 | wiring | Power signal camera and servo-bus harnesses |  |  |  |  | 1 | set |  | TODO | Awaiting harness trace | Split by cable with connector family wire gauge length labels and revision

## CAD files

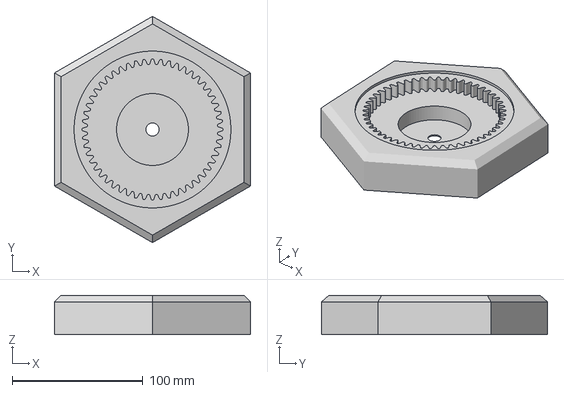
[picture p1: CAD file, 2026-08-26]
hardware/3mf/co-arm_base_main-body_r01.3mf
150.0 x 173.2 x 30.0 mm

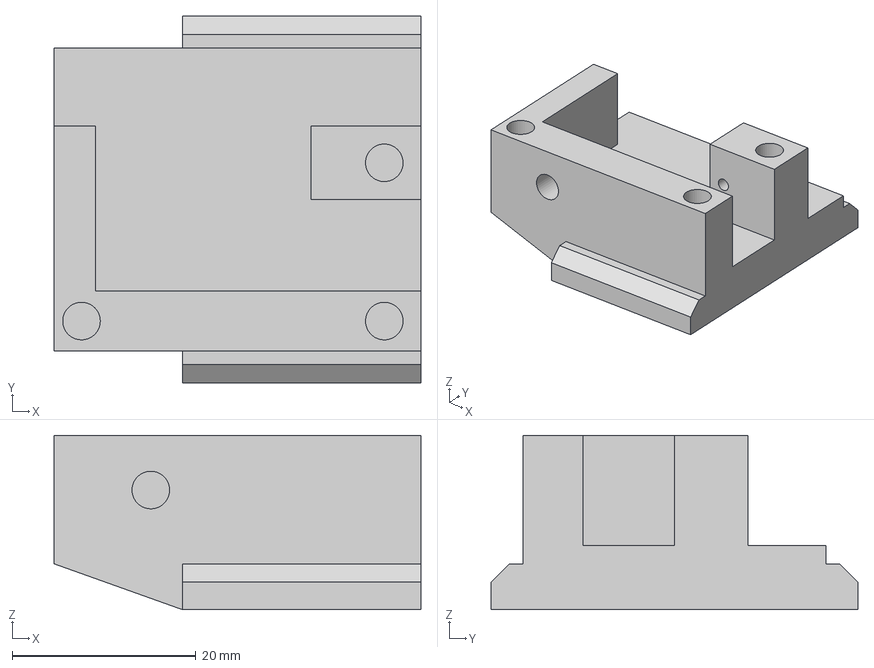
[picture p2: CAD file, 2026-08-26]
hardware/3mf/co-arm_camera_servo-mount_r01.3mf
40.0 x 40.0 x 19.0 mm

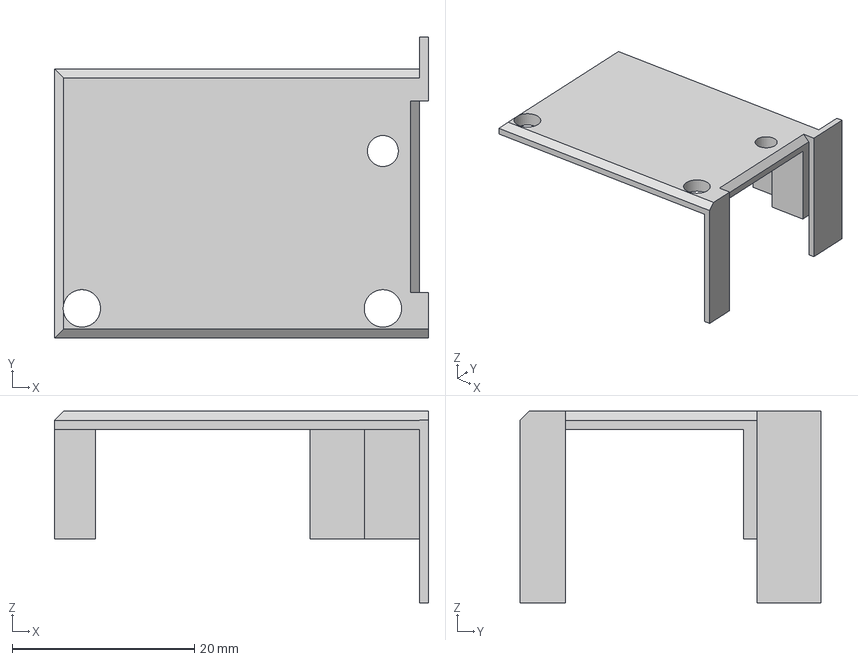
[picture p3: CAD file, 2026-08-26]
hardware/3mf/co-arm_elbow_servo-cover_r01.3mf
41.0 x 33.0 x 21.0 mm

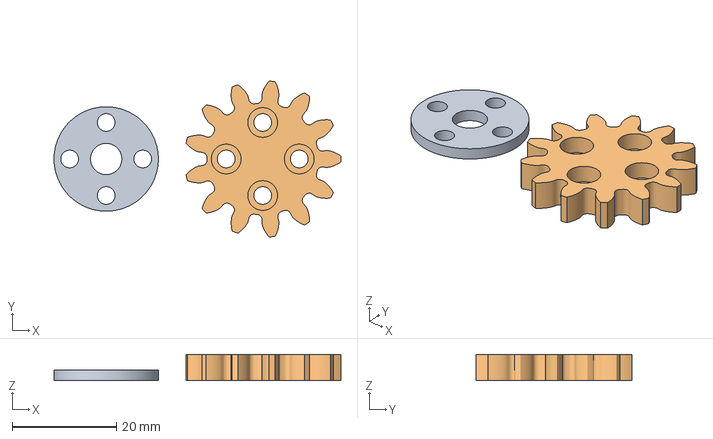
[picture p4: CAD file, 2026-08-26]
hardware/3mf/co-arm_base_servo-gear_r01.3mf
55.0 x 29.9 x 5.00 mm
Spur Gear (13 teeth) (1)
Spur Gear (13 teeth)

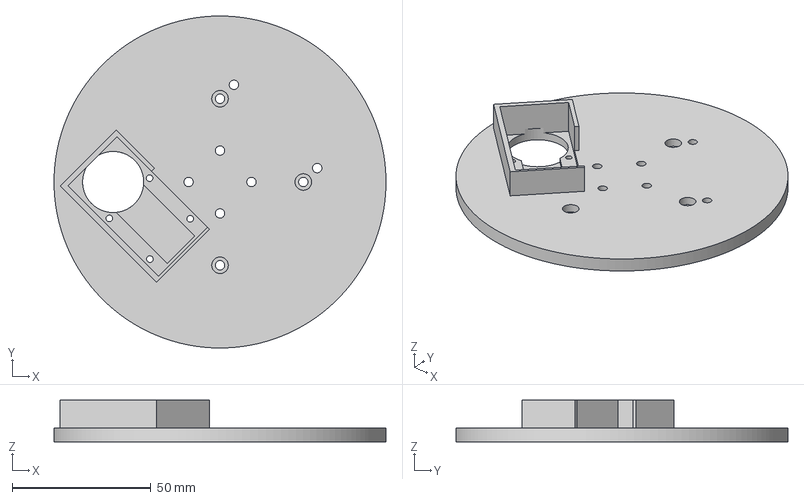
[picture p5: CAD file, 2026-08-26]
hardware/3mf/co-arm_base_level-2-platform_r01.3mf
119.6 x 119.6 x 15.0 mm

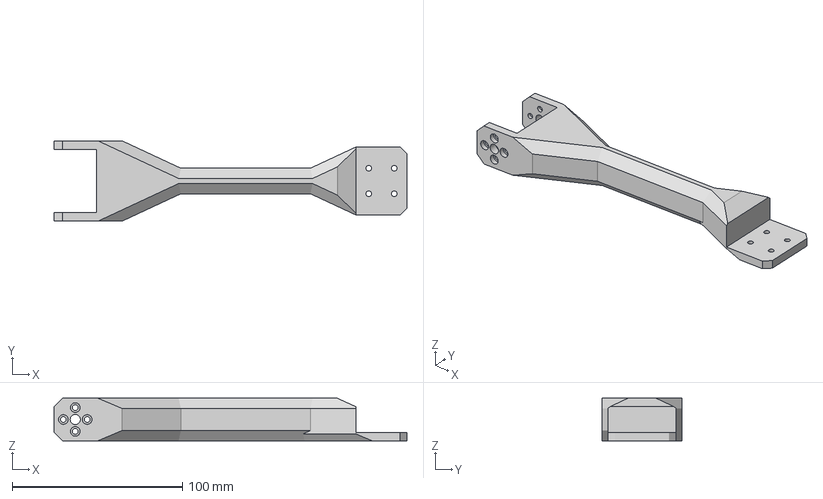
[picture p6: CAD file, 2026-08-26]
hardware/3mf/co-arm_elbow_upper-link_r01.3mf
207.5 x 47.2 x 25.0 mm

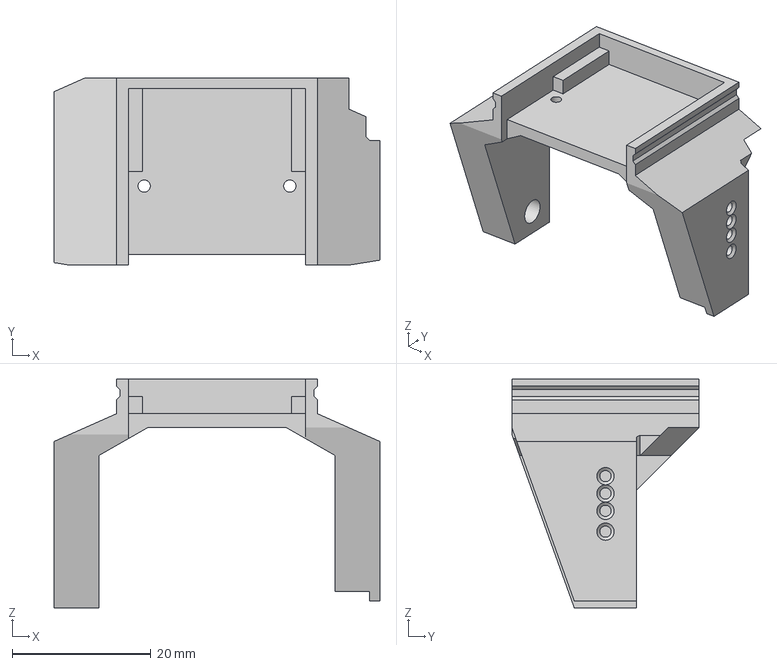
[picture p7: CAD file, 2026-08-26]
hardware/3mf/co-arm_camera_holder_r01.3mf
47.0 x 27.0 x 33.0 mm

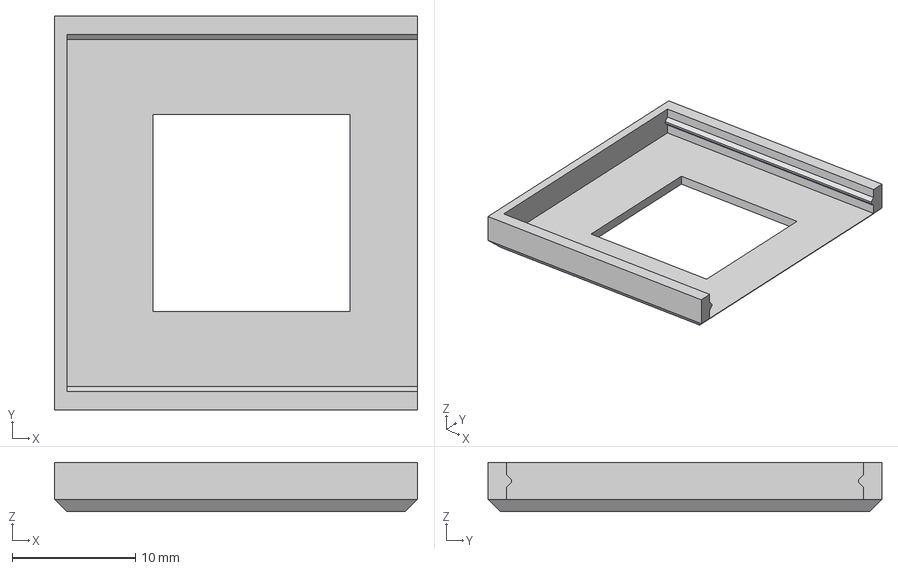
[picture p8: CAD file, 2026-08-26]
hardware/3mf/co-arm_camera_cover_r01.3mf
29.5 x 32.0 x 4.00 mm

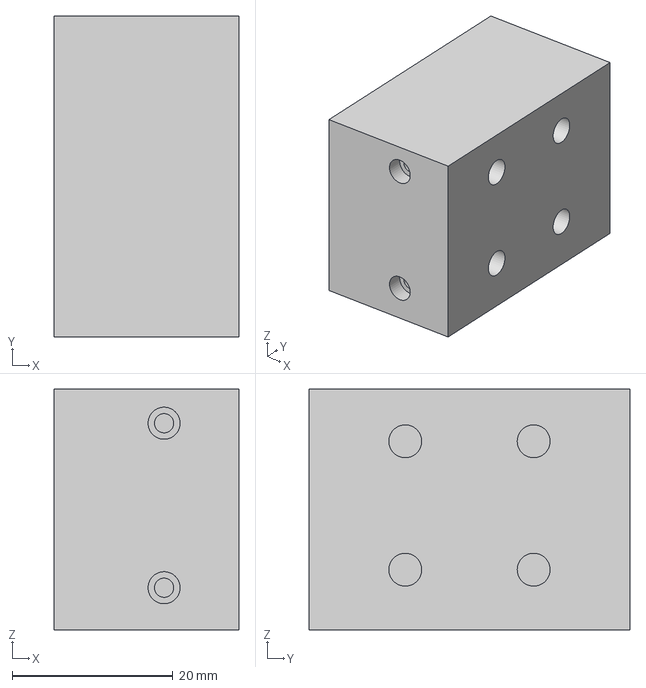
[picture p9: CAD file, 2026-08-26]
hardware/3mf/co-arm_shoulder_servo-mount_r01.3mf
23.0 x 40.0 x 30.0 mm

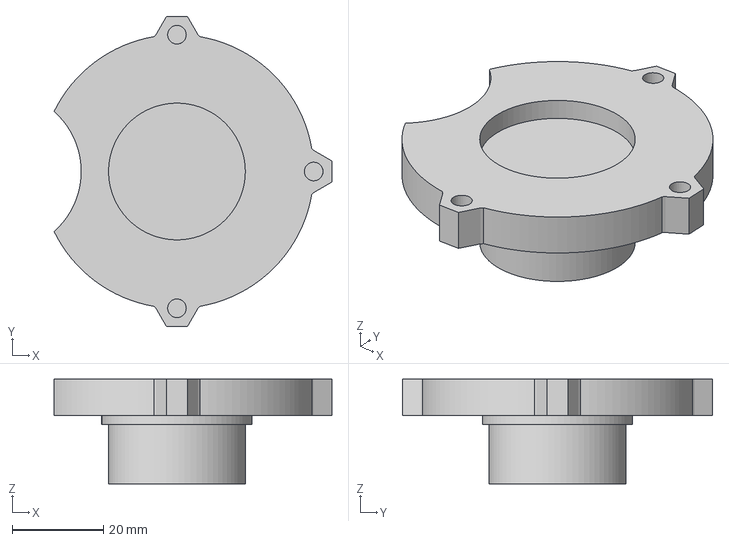
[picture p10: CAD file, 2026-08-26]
hardware/3mf/co-arm_base_shaft-base_r01.3mf
61.0 x 68.0 x 23.0 mm

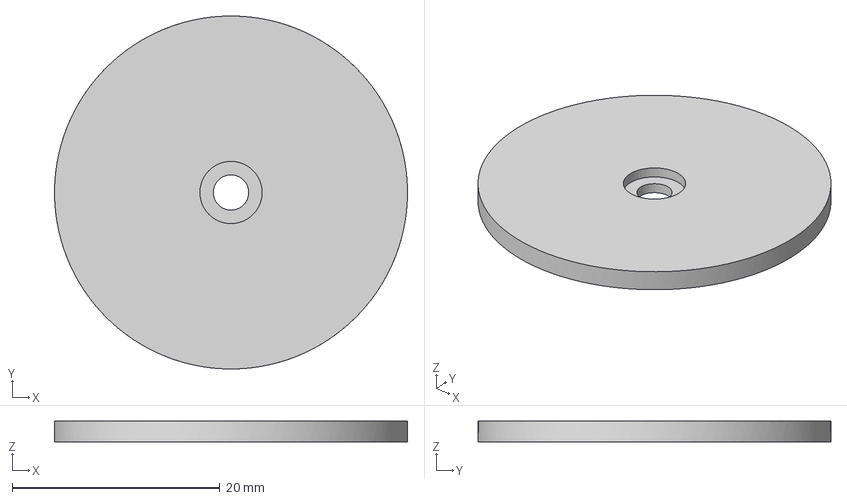
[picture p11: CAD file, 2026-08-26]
hardware/3mf/co-arm_base_bearing-bottom_r01.3mf
34.0 x 34.0 x 2.00 mm

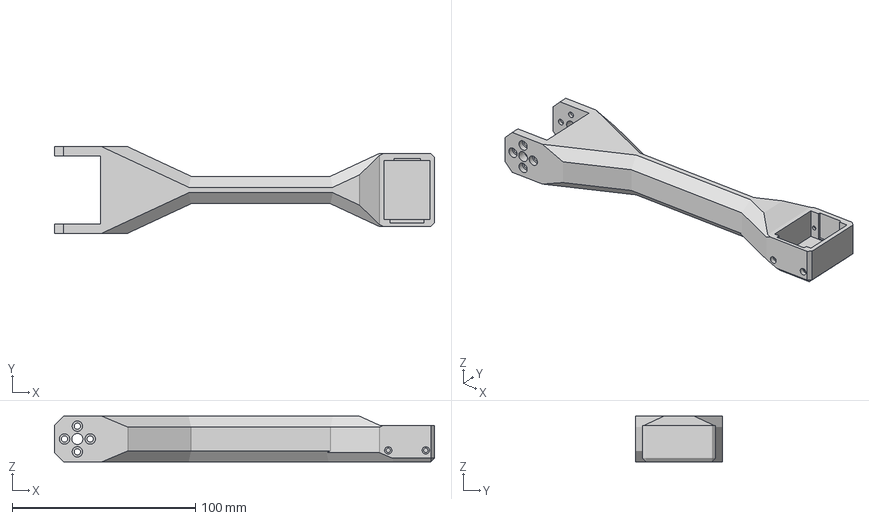
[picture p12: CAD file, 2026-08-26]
hardware/3mf/co-arm_shoulder_lower-link_r01.3mf
207.5 x 47.2 x 25.0 mm

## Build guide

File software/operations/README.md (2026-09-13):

# ARM operations

This directory contains the source-only deployment and recovery tools for the
Raspberry Pi arm gateway, core Isaac Sim launcher, and ESP32 Arm HAT firmware
build.

All installation-specific values are inputs. Supply the target host, service
account/group, SSH identity, pinned known-hosts file, controller/firmware
identity, and network addresses explicitly; do not commit those values or the
generated runtime artifacts. The scripts keep tokens, manifests, backups, disk
images, logs, and build output under an ignored runtime directory or a caller-
selected build directory.

Run scripts from any working directory; paths to source files are resolved from
the script location. The shared source-root convention is `software/`, with
Python packages in `software/python/`, operational files here, and firmware in
`software/firmware/`.

The deployment scripts configure only the arm gateway. The base service is
loopback-only and starts with the physical UART dormant. First activation and
its dormant rollback use the separate, approval-gated gateway-mode operation.

`scripts/arm_status.py` is read-only unless `--scan` is supplied. A scan is a
commissioning mutation: it clears outstanding motion proposals, may request
torque-off, and can invalidate Base truth until it is re-established.
Its bearer-token gateway URL is restricted to plain HTTP on an explicit local
loopback port; it rejects URL suffixes and bypasses redirects and proxies.

## Tool map

- `scripts/run_arm_sim.py` creates simulator-only tokens, supervises the core
  Isaac bridge and HTTP gateway, and writes its scene, state, and logs only
  under `software/runtime/arm-sim/`.
- `scripts/deploy-arm-gateway.ps1` installs the reviewed gateway package and
  loopback-only service. It stops and restarts the service; a live hold can
  expire and a gravity-loaded arm can sag, so support the mechanism first.
- `scripts/set-arm-gateway-mode.ps1` reversibly activates or deactivates only
  the reviewed physical-UART drop-in on an existing prepared Pi. It preserves
  the fail-closed latch and accepts activation only after authenticated live
  proof of the exact controller, firmware, required capabilities, and four
  fresh stationary torque-off joints. It never clears STOP, takes torque, or
  moves.
- `scripts/arm_status.py` separates gateway, controller, bus, STOP, and joint
  state. Use the default read-only form before considering `--scan`.
- `scripts/restore-arm-pi.ps1`, `scripts/backup-arm-pi.ps1`, and
  `scripts/image-arm-pi-sd.ps1` contain the Pi recovery tooling. Portable
  recovery is incomplete; see the release blocker below.
- `scripts/compile-firmware.ps1` builds only the ESP32 Arm HAT source and never
  flashes it.

For the ordered agent-assisted setup flow, start at
[`../../docs/SETUP_WITH_CODEX.md`](../../docs/SETUP_WITH_CODEX.md).

## Pi source and snapshot contract

Make reusable gateway changes in this checkout, validate them, and deploy those
exact bytes. `backup-arm-pi.ps1` computes a canonical SHA-256 contract for the
reviewed 13 gateway modules plus `requirements-pi.txt` and refuses the snapshot
if the frozen deployed copies differ. A live-Pi edit is therefore drift to fix,
not a new source of truth.

Take a protected snapshot before each reachable persistent Pi mutation when a
useful prior state exists, then always take and verify another after the change.
The parameterized archive retains same-device calibration, recovery gates,
service/network/boot evidence, optional Base and recovery markers, credentials,
and media binding under ignored `software/runtime/robot-gateway/pi-backups/`.
It is private recovery state for that Pi, not a template for another person's
credentials, Base frame, network, or host identity.

## Recovery acceptance still pending

The September 5 source fixes cover the earlier recovery findings:

- Backup accepts a fresh deployment without historical recovery metadata and
  records stale provenance without silently rewriting it.
- Portable Prepare verifies a protected archive and derives provenance from
  its frozen calibration; prepared inputs are bound by their digests.
- Restored Base calibration has an independent reference gate. Clearing STOP
  cannot establish Base truth; explicit physical re-zero and durable readback
  are required, and execution rechecks the gate before dispatch.

These paths have local regressions, including Windows archive/permission
checks. A complete backup-to-replacement-device round trip has not been
accepted. The public prototype includes this experimental source but does not
offer it as a supported physical recovery kit. A valid archive checksum proves
saved bytes, not physical continuity or successful restoration.

The snapshot requirement above remains in force. Keep existing protected
archives and follow the remaining device-acceptance work in the
[release review](../../docs/RELEASE_REVIEW.md).

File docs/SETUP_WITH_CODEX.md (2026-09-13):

# Set up and run co-arm with an agent

This guide takes the repo from a clean checkout to source checks, the dashboard,
Isaac Sim, or a real Raspberry Pi arm.

To open the dashboard first, use the shorter [quickstart](QUICKSTART.md).
Return here for validation, simulation, Pi setup, or the Codex connection.

All 12 current printed parts are included. The bearing details, screw/insert
list, print settings, wiring drawing, and power details are still being added.

## Pick your path

- **Source only:** clone, install, and run the checks in section 1. Section 2
  is an optional no-gateway dashboard smoke. No
  simulator, Raspberry Pi, controller, camera, or servo is contacted.
- **Dashboard only:** complete source setup, then run section 2's local
  dashboard with no configured backend. Controls remain unavailable.
- **Simulation:** complete source setup, then follow section 3 and configure
  MCP with `ARM_EXPECTED_BACKEND=sim`.
- **Existing configured arm:** validate source first, inventory the live build,
  then use the [existing-arm short path](#existing-arm-short-path) with
  `ARM_EXPECTED_BACKEND=real`.
- **New physical build:** use the 3MF parts and assembly map, then fill in the
  bearing, fastener, print, wiring, and power details that are still marked
  TODO.

### Existing-arm short path

For an already commissioned arm, start with section 1's source checks and
section 8's tunnel, read-only status, and dashboard connection. Check that the
installed source, hardware, calibration, and camera match the build you intend
to use. Section 5 helps diagnose a connection or device fault. Section 9 adds
the optional Codex connection.

Sections 4, 6, 7, and 10 cover physical inventory, firmware, deployment, and
commissioning. Revisit the relevant stage when that part of the installation
has changed or lacks evidence; reconnecting a working arm does not by itself
require reflashing it or repeating all calibration. A lost Base reference still
requires physical alignment with its zero mark and **Set zero here**.

## What you provide

- which path you want: source, dashboard, simulation, existing arm, or new
  build;
- the real hardware details that code cannot see, such as bearing size, wiring,
  zero marks, and whether the arm is assembled;
- the physical task you want the arm to do.

## What Codex does

- reads the repo and chooses the matching path;
- runs the source checks and tells you plainly what passed;
- for a configured arm, reads the current joints/camera, shows the move, runs
  it, and checks what happened;
- asks only when a missing physical fact changes the next step or the tool
  needs an exact confirmation.

## 0. Start the agent

Open the repository root in Codex or another coding agent and use:

```text
Help me run co-arm. Read AGENTS.md and docs/SETUP_WITH_CODEX.md, then check
whether I am using source only, Isaac Sim, or the real arm. Take the matching
path and keep updates short. If the real arm is already configured, read its
current state, show the move, run it, and check the joints or camera afterward.
Treat the physical task I ask for as the go-ahead for its normal steps. Stop
only if a real fault or missing physical fact changes the job.
```

Do not paste credentials, private keys, private endpoints, unique device IDs,
or unreviewed camera frames into prompts, issues, or committed files.

## 1. Clone and validate without hardware

Requirements:

- Git;
- Python 3.11 for the validated lock; the package declares 3.11 or newer, but
  another interpreter needs its own clean verification;
- Node.js 20.19.x or 22.12 or newer (Node 21 and Node 22.0-22.11 are not
  supported by the locked Vite version);
- pnpm matching `software/dashboard/package.json`;
- Windows PowerShell 5.1 or newer and OpenSSH `ssh`/`scp` for the retained
  deployment and recovery scripts;
- a Codex CLI build exposing `plugin` and `mcp` commands when installing the
  optional repo-local plugin/MCP integration;
- a C++17 compiler for complete firmware host-test proof; without one, the
  compile portions are reported as skipped;
- Isaac Sim and Arduino tooling only for their respective later stages.

On Windows PowerShell:

```powershell
git clone https://github.com/over-TT/co-arm.git
Set-Location co-arm

python -m venv .venv
.\.venv\Scripts\python.exe -m pip install --upgrade pip
.\.venv\Scripts\python.exe -m pip install --requirement ".\software\python\requirements.lock"
.\.venv\Scripts\python.exe -m pip install --no-deps --editable ".\software\python"

.\.venv\Scripts\python.exe tools\build_source_manifest.py --check
.\.venv\Scripts\python.exe tools\check_repo.py

Set-Location software\python
..\..\.venv\Scripts\python.exe -m pytest -q -p no:cacheprovider
..\..\.venv\Scripts\python.exe -m pytest -q -p no:cacheprovider ..\firmware\tests\test_arm_hat_controller_v1.py
Set-Location ..\dashboard
pnpm install --frozen-lockfile
pnpm test
pnpm build
Set-Location ..\..
```

The validation block can be translated to POSIX by using `.venv/bin/python`.
The deployment, recovery, ACL, and tunnel examples later in this guide are
Windows/PowerShell-first. On another OS, translate the whole command, including
paths, quoting, and required privileges. Commands shown as `sh` run on the Pi.

A passing checkout proves the tested source in that host environment. It does
not prove that a Pi service is installed, firmware is flashed, a controller or
servo bus is healthy, a joint arrived, or the camera saw anything.
The firmware host test also attempts its C++17 compile checks. If no compatible
C++ compiler is installed, pytest reports those checks as skipped; record that
toolchain boundary instead of treating the skipped compile as firmware proof.

## 2. Run the dashboard with no upstream gateway

The dashboard can be served locally before SIM or REAL is configured:

```powershell
.\.venv\Scripts\python.exe -m web_backend
```

Open `http://127.0.0.1:8765/`. With no gateway pair configured, physical and
simulated arm-control routes remain unavailable. The Control Center may still
list its fixed local setup/check actions, such as starting Isaac or running
source tests, when their required local tools are present. This proves the UI
shell and local setup surface, not an arm connection.

Keep that terminal running; **Ctrl+C** stops the dashboard. If the port is
already in use, add `--port 8766` and open `http://127.0.0.1:8766/` instead.

The dashboard contains arm controls only. The supported agent integration is
the repository instructions plus the external MCP plugin; no embedded Codex
binary, login, memory, or chat runtime is bundled.

## 3. Run the Isaac Sim arm

### 3.1 Resolve the Isaac launcher

The user must provide the installed Isaac Python launcher. Record its exact
Isaac Sim version/build, install source/path, GPU/driver environment, and
whether the launcher can import the installed modules. The source uses Isaac
Sim 6 experimental articulation, stage, and RTX camera APIs; this export does
not claim that every Isaac 6 build has the same surface. Treat the smoke
self-test below as the compatibility gate for the selected installation.

### 3.2 Create ignored local tokens

From `software/`:

```powershell
$env:PYTHONPATH = "python"
..\.venv\Scripts\python.exe operations\scripts\run_arm_sim.py --ensure-tokens
$simRuntime = (Resolve-Path ".\runtime\arm-sim").Path
$account = [System.Security.Principal.WindowsIdentity]::GetCurrent().Name
icacls $simRuntime /inheritance:r /grant:r "${account}:(OI)(CI)F"
Get-ChildItem -LiteralPath $simRuntime -Filter *.token -File | ForEach-Object {
  icacls $_.FullName /inheritance:r /grant:r "${account}:(R,W)"
}
```

This writes owner-local simulator credentials under ignored
`software/runtime/arm-sim/`. It does not start Isaac or contact the physical
arm. Never commit or print those files.

Resolve the installed launcher and editor experience, export both for the
Control Center, and run the deterministic headless scene/camera artifact test
before starting the persistent stack:

```powershell
$isaacPython = "<absolute-path-to-isaac-python>"
$isaacExperience = "<absolute-path-to-isaacsim.exp.full.kit>"
$env:ISAAC_PYTHON = $isaacPython
$env:ISAAC_EXPERIENCE = $isaacExperience
& $isaacPython .\python\arm_sim\isaac\smoke_scene.py --headless
```

Passing proves that the selected Isaac installation initialized this source and
wrote the allowlisted scene, RGB render, and report under
`software/runtime/arm-sim/`. It is not persistent-bridge or physical-arm proof;
the next stage verifies the persistent bridge separately.

### 3.3 Start the persistent simulator stack

```powershell
..\.venv\Scripts\python.exe operations\scripts\run_arm_sim.py `
  --isaac-python $isaacPython
```

Add `--gui` for an interactive window. The launcher owns only the local Isaac
bridge, simulator HTTP gateway, and ignored simulator runtime files. It never
connects to the Raspberry Pi.

Expected loopback endpoints:

| Port | Purpose |
| ---: | --- |
| 8788 | simulator gateway used by dashboard/MCP |
| 8790 | authenticated Isaac bridge |
| 8791 | authenticated launcher control/stop |

### 3.4 Attach the dashboard to SIM

From the repository root in another PowerShell:

```powershell
$env:ISAAC_PYTHON = "<absolute-path-to-isaac-python>"
$env:ISAAC_EXPERIENCE = "<absolute-path-to-isaacsim.exp.full.kit>"
.\.venv\Scripts\python.exe -m web_backend `
  --sim-url http://127.0.0.1:8788 `
  --sim-token-file .\software\runtime\arm-sim\gateway.token
```

Open `http://127.0.0.1:8765/#arm/overview` and verify, in order:

1. SIM inventory and exact source/process identity;
2. arm state from the persistent Isaac instance;
3. camera status and one smoke capture;
4. one motionless plan preview;
5. only then, an explicitly selected simulated apply.

A simulated JPEG or arrival is SIM evidence only.

### 3.5 Stop SIM

From `software/`:

```powershell
..\.venv\Scripts\python.exe operations\scripts\run_arm_sim.py --stop
```

The authenticated supervisor should close ports 8788, 8790, and 8791. Do not
substitute arbitrary process termination unless the exact local process has
been identified and the supervised path is broken.

## 4. Inventory a physical build

Before Pi deployment or servo work, resolve:

- exact Pi, HAT, camera, and all four servo labels/revisions;
- logical joint-to-servo ID mapping;
- supply voltage/current, polarity, regulator path, wire ratings,
  fuse/protection, common ground, and reachable physical servo-power cut;
- Base ratio and durable zero mark;
- joint hard stops, safe inward limits, cable limits, and gravity support;
- camera/bracket orientation and measured 60/180/220 mm geometry;
- whether the published parts and wiring actually match this mechanism.

Use [ASSEMBLY.md](ASSEMBLY.md), [ELECTRONICS.md](ELECTRONICS.md), and the BOM.
If a required fact is unresolved, stop at the last non-motion stage.

## 5. Read-only Raspberry Pi discovery

Start with servo power off and gravity-loaded links supported. Use an SSH
identity and pinned known-hosts file; do not disable host-key checking.

### 5.1 Blank-Pi prerequisite gate

The deployer does not create an OS user/group or install the Raspberry Pi OS
camera stack. On a clean Pi, first confirm all of the following without
connecting the servo rail:

- SSH and SCP work through a verified host key;
- the selected service user and primary group already exist;
- that user has the reviewed non-interactive `sudo` access required by the
  deployer;
- `systemd`, `curl`, `install`, Python 3.11+, `venv`, and `pip` are available;
- the `dialout`, `video`, and `render` groups exist and the service identity has
  the access needed by the installed UART and camera devices;
- Picamera2/libcamera and `rpicam-apps` come from Raspberry Pi OS packages, not
  the project virtual environment;
- the camera is detected before the gateway service is introduced.

Useful no-write checks on the Pi are:

```sh
id
getent group dialout video render
sudo -n true
command -v systemctl curl install python3
python3 --version
python3 -m venv --help >/dev/null
python3 -c 'import picamera2; print(picamera2.__file__)'
rpicam-hello --list-cameras
```

If a prerequisite is missing, the agent must show the exact OS package,
user/group, or sudoers change and its rollback before asking for authority. Do
not hide operating-system provisioning inside the arm deployment receipt.

### 5.2 Inspect the installed Pi state

On the Pi:

```sh
uname -a
cat /etc/os-release
python3 --version
rpicam-hello --list-cameras
systemctl status arm-gateway.service --no-pager
ss -ltn
```

Then diagnose layer by layer:

1. laptop-to-Pi SSH/tunnel transport;
2. Pi gateway process;
3. Pi-to-ESP32 Arm HAT UART;
4. controller identity and STOP state;
5. servo-bus scan and IDs;
6. fresh torque/motion/position telemetry;
7. Base continuity;
8. Camera Module 3 status and capture.

`/healthz` proves only the gateway/tunnel layer. Inspect the status helper before
using it:

```powershell
.\.venv\Scripts\python.exe software\operations\scripts\arm_status.py --help
```

Running the helper without `--scan` only reads current gateway state. `--scan`
actively checks the servo bus and may recover the controller, turn torque off,
and make the Base need its physical zero mark again. Use it when a bus scan is
actually wanted, and hold a raised arm because the links can go limp.

## 6. Build the ESP32 Arm HAT firmware

The repository does not vendor Arduino CLI or the ESP32 core. Install them from
their official source. The helper records whichever Arduino CLI executable the
caller supplies and strictly requires ESP32 core `3.3.11`; it does not claim a
tested universal Arduino CLI version.

Compile to a caller-selected directory outside the source tree:

```powershell
$arduinoCli = (Resolve-Path "<absolute-path-to-arduino-cli>").Path
$firmwareBuildRoot = "<absolute-temporary-build-directory-outside-co-arm>"
.\software\operations\scripts\compile-firmware.ps1 `
  -ArduinoCli $arduinoCli `
  -BuildRoot $firmwareBuildRoot
```

The helper builds the Arm HAT target and never uploads. Record the source
commit, toolchain/core versions, artifact size, and digest.

Flashing is a separate device write. Before upload, the agent must identify the
exact board and port, exclude competing UART hosts, preserve required device
regions, show the exact upload/readback command and rollback, and receive
deliberate operator approval. This export does not guess a universal port or
flash command.

## 7. Deploy the Raspberry Pi gateway

Inspect current help:

```powershell
Get-Help .\software\operations\scripts\deploy-arm-gateway.ps1 -Detailed
```

The reviewed dormant deployment shape is:

```powershell
$sshPort = <ssh-port>
$identityFile = (Resolve-Path "<absolute-private-key-path>").Path
$knownHostsFile = (Resolve-Path "<absolute-pinned-known-hosts-path>").Path
.\software\operations\scripts\deploy-arm-gateway.ps1 `
  -HostName <pi-host-or-address> `
  -UserName <pi-service-user> `
  -ServiceGroup <pi-service-group> `
  -IdentityFile $identityFile `
  -KnownHostsFile $knownHostsFile `
  -Port $sshPort
```

The default path installs the package and loopback service but keeps physical
UART dormant. It does not flash firmware, enable torque, or command motion.
It does stop and restart the gateway service; on an already active physical
installation that can let a hold/watchdog expire and a gravity-loaded arm sag.
Support the mechanism and establish the expected service/torque state before
authorizing deployment or restart.
`-PreservePhysicalUart` is only for an already-installed, byte-identical
reviewed drop-in; it is not first-time activation.

Fresh physical-UART activation is a separate, reversible commissioning gate for
an existing prepared Pi. Use one reviewed argument set for activation and its
dormant rollback:

```powershell
$armMode = @{
  HostName = "<pi-host-or-address>"
  Port = $sshPort
  UserName = "<pi-service-user>"
  ServiceGroup = "<pi-service-group>"
  IdentityFile = $identityFile
  KnownHostsFile = $knownHostsFile
  ExpectedControllerId = "<exact-controller-id>"
  ExpectedFirmwareVersion = "<exact-firmware-version>"
}

.\software\operations\scripts\set-arm-gateway-mode.ps1 `
  @armMode -Mode Activate

# Reversible dormant rollback.
.\software\operations\scripts\set-arm-gateway-mode.ps1 `
  @armMode -Mode Deactivate
```

The operation does not configure the UART overlay or serial console. Activation
refuses until those prerequisites and `/dev/serial0` are already correct. It
verifies the exact installed base unit and staged drop-in digest, seeds or
retains the fail-closed latch, restarts deliberately, then authenticates the
expected controller/firmware, required controller capabilities, and four fresh
torque-off stationary joints with STOP and inspection latched. Deactivation
removes only that reviewed drop-in,
retains the latch, restarts dormant, and proves that no physical controller port
or unexpected drop-in remains. Already-correct modes are verified without a
restart. Neither mode reboots, deploys, clears STOP, takes torque, moves, or
uses the camera.

After deployment, verify separately:

- installed source hashes;
- service status and restart count;
- loopback-only listener;
- token ownership/mode without printing its content;
- controller link, servo bus, STOP/torque/telemetry, and camera state.

### 7.1 Keep every Pi mutation recoverable

**Device acceptance is still a release blocker.** The archive preparation,
provenance, and Base-reference guards now have local regression coverage, but
no complete replacement-Pi recovery was performed for this candidate. Treat
physical restore as supervised validation, not a proven disaster-recovery kit.
The [release review](RELEASE_REVIEW.md) records the remaining proof.

The checkout is the reusable source of truth. Do not edit an ordinary gateway
module only on the Pi. Before a reachable persistent Pi change, take a protected
snapshot when useful prior state exists; after a successful deployment,
calibration, Base-reference, service/UART/boot, or network change, always take
and verify a new one. A failed required snapshot leaves the change incomplete.
The current backup command is:

```powershell
$piBackup = @{
  HostName = "<pi-host-or-address>"
  Port = $sshPort
  UserName = "<pi-service-user>"
  ServiceGroup = "<pi-service-group>"
  IdentityFile = $identityFile
  KnownHostsFile = $knownHostsFile
  ExpectedHostName = "<exact-pi-hostname>"
  ExpectedRootDevice = "<exact-root-device>"
  ExpectedBootDevice = "<exact-boot-device>"
  DirectLanAddressCidr = "<expected-address/cidr>"
  DirectLanProfilePath = "<exact-/etc/netplan/profile.yaml>"
}
.\software\operations\scripts\backup-arm-pi.ps1 @piBackup
```

The backup freezes the deployed files and refuses to complete unless all 13
reviewed gateway modules and `software/operations/requirements-pi.txt` match
the exact SHA-256 hashes from this checkout. It also records device-specific
calibration, safety/recovery gates, services, network/SSH/VNC state, boot and
optional USB-media evidence. Archives live under the ignored, owner-only
`software/runtime/robot-gateway/pi-backups/`; they contain secrets and machine
identity and must only rebuild that same Pi. Another person's Pi starts from
the reviewed source and creates its own credentials, commissioning evidence,
and protected snapshot history.

A fresh deployment does not need old restore metadata to create a backup.
When older calibration provenance exists, backup preserves its bytes and
records whether its hash is current, stale, malformed, or absent. It does not
rewrite that history as a new physical attestation.

Prepare restore inputs locally, using the SHA-256 retained when the same Pi's
protected archive was verified. Recomputing a checksum from an untrusted file
does not authenticate its origin. This phase does not contact the Pi:

```powershell
$piRestore = @{
  HostName = "<pi-host-or-address>"
  Port = $sshPort
  UserName = "<pi-service-user>"
  ServiceGroup = "<pi-service-group>"
  IdentityFile = $identityFile
  KnownHostsFile = $knownHostsFile
  TokenFile = "<protected-token-file-for-this-pi>"
  ExpectedHostName = "<exact-pi-hostname>"
  ExpectedRootDevice = "<exact-replacement-root-device>"
  ExpectedBootDevice = "<exact-replacement-boot-device>"
  ExpectedControllerId = "<verified-controller-id>"
  ExpectedFirmwareVersion = "<verified-firmware-version>"
  DirectLanAddressCidr = "<expected-address/cidr>"
  RecoveryArchivePath = "<protected-backup.tar.gz>"
  RecoveryArchiveSha256 = "<retained-lowercase-64-character-sha256>"
  PythonExecutable = "<python-3.11-or-newer-executable>"
}
.\software\operations\scripts\restore-arm-pi.ps1 -Phase Prepare @piRestore
```

The helper reads the frozen calibration without extracting an arbitrary
archive tree. It checks archive/member integrity and the recorded hostname and service user,
then generates archive-bound provenance and an independent Base-reference
marker under the protected ignored recovery directory. Normally omit both
`CalibrationFile` and `CalibrationProvenanceFile`; if supplied, they must match
the selected archive exactly. Archived stale provenance is historical data,
not a reason to fabricate a replacement attestation.

Later phases reuse the prepared manifest and refuse changed source, token,
calibration, or marker inputs. Bootstrap installs the Base marker before the
gateway resumes. Clear STOP does not remove it: place Base on its physical
zero mark and use the explicit **Set zero here** action. Verified homing,
durable calibration readback, and marker removal are all required to unlock
motion; malformed recovery state must be repaired first.

`Verify` checks the prepared, pre-commissioning recovery state. After re-zero,
the calibration and marker deliberately change: create and verify a new
protected backup instead of expecting the old recovery manifest to match.
Archive integrity and local tests still do not establish a physical round trip.

## 8. Connect the laptop to REAL

The deployer creates or preserves the Pi token at
`/home/<pi-user>/arm-gateway/.robot-gateway.token` with mode `0600` and never
prints it. Copy it before starting the blocking tunnel, over the same pinned
SSH trust path, to an explicit location outside the repository. Direct OpenSSH
treats `UserKnownHostsFile` as a space-separated list, so this manual path must
not contain whitespace; the deployer itself has a separate safe staging
workaround for paths with spaces.

```powershell
$sshPort = <ssh-port>
$identityFile = (Resolve-Path "<absolute-private-key-path>").Path
$knownHostsFile = (Resolve-Path "<absolute-pinned-known-hosts-path-with-no-spaces>").Path
if ($knownHostsFile -match '\s') {
  throw "Use an owner-controlled pinned known-hosts path with no whitespace for direct ssh/scp."
}
$localToken = "<absolute-owner-only-path-outside-the-repository>"
scp -P $sshPort `
  -i $identityFile `
  -o "UserKnownHostsFile=$knownHostsFile" `
  -o StrictHostKeyChecking=yes `
  <pi-user>@<pi-host>:/home/<pi-user>/arm-gateway/.robot-gateway.token `
  $localToken
$account = [System.Security.Principal.WindowsIdentity]::GetCurrent().Name
icacls $localToken /inheritance:r /grant:r "${account}:(R)"
```

On POSIX, use the equivalent pinned `scp` command followed by `chmod 600`.
Verify file ownership and permissions without printing the token.

Next, open a dedicated PowerShell for the blocking loopback tunnel and leave it
running. Define the trust variables again so the command is independently
copyable:

```powershell
$sshPort = <ssh-port>
$identityFile = (Resolve-Path "<absolute-private-key-path>").Path
$knownHostsFile = (Resolve-Path "<absolute-pinned-known-hosts-path-with-no-spaces>").Path
if ($knownHostsFile -match '\s') {
  throw "Use an owner-controlled pinned known-hosts path with no whitespace for direct ssh/scp."
}
ssh -N `
  -L 8787:127.0.0.1:8787 `
  -p $sshPort `
  -i $identityFile `
  -o "UserKnownHostsFile=$knownHostsFile" `
  -o StrictHostKeyChecking=yes `
  <pi-user>@<pi-host>
```

In a third PowerShell, define the token path again, run the authenticated
read-only status first, and only then start the dashboard:

```powershell
$localToken = "<absolute-owner-only-path-outside-the-repository>"
.\.venv\Scripts\python.exe .\software\operations\scripts\arm_status.py `
  --gateway-url http://127.0.0.1:8787 `
  --token-file $localToken

.\.venv\Scripts\python.exe -m web_backend `
  --real-url http://127.0.0.1:8787 `
  --real-token-file $localToken
```

Before motion, require REAL upstream identity, fresh controller/bus state,
STOP/torque state, calibration, Base continuity, and camera state. A tunnel or
health response alone is insufficient.

## 9. Configure the external MCP agent

The Python installation provides `python -m arm_mcp`. First install the
repo-local instruction plugin from the repository root:

```powershell
codex plugin marketplace add .\software\plugin
codex plugin add arm-alliance@co-arm
```

The plugin is `software/plugin/plugins/arm-alliance/` and contains no live MCP
configuration. Configure these values in machine-local MCP configuration,
never in Git:

- `ARM_GATEWAY_URL` — SIM `http://127.0.0.1:8788` or REAL
  `http://127.0.0.1:8787`;
- `ARM_EXPECTED_BACKEND` — exactly `sim` or `real`, selected independently of
  the port so a valid token connected to the wrong gateway is refused;
- `ARM_GATEWAY_TOKEN_FILE` — absolute owner-readable token path;
- `ARM_FRAME_DIR` — ignored local retained-frame directory.

Create an ignored frame directory and register the server with the exact
project interpreter. Select the SIM or REAL URL/token file established above:

```powershell
$projectPython = (Resolve-Path .\.venv\Scripts\python.exe).Path
$frameDir = Join-Path $env:LOCALAPPDATA "co-arm\frames"
New-Item -ItemType Directory -Force -Path $frameDir | Out-Null
codex mcp add co-arm `
  --env "ARM_GATEWAY_URL=<selected-loopback-gateway-url>" `
  --env "ARM_EXPECTED_BACKEND=<sim-or-real>" `
  --env "ARM_GATEWAY_TOKEN_FILE=<absolute-owner-readable-token-file>" `
  --env "ARM_FRAME_DIR=$frameDir" `
  -- $projectPython -m arm_mcp
codex mcp get co-arm
```

`codex mcp remove co-arm` is the machine-local rollback. Never commit an
absolute interpreter, endpoint, frame path, or credential path. Start a new
Codex task after plugin/MCP changes so the client reloads the skills and tools.

Check a new agent task in this order:

1. plugin/skill is visible;
2. MCP starts from the intended interpreter;
3. `arm_state` says whether it is connected to SIM or the real arm;
4. `arm_scene` is motionless;
5. preview shows the move before apply runs it.

`arm_release` turns servo torque off. Shoulder and Elbow go limp, so hold them
if they are raised; the tool asks for `confirmed_torque_release=true`.
`arm_set_base_zero` is different: line up the physical Base mark first, then
confirm it. Turning the floor guard off also asks for confirmation. Normal
look/preview/move work should not become a repeated permission loop.

The plugin's setup skill follows this runbook and `AGENTS.md`; its runtime
skill and live MCP tools apply only after the selected gateway is configured.

## 10. Commission and run

Follow [COMMISSIONING.md](COMMISSIONING.md). The condensed order is:

1. non-motion controller handshake;
2. one isolated servo identity at a time;
3. fresh readback and torque-off proof;
4. zero, direction, ratio, and inward-limit calibration;
5. Base physical mark and native-frame truth;
6. measured geometry and floor reference;
7. small single-joint reviewed motions;
8. slow coordinated plan/apply;
9. upright Camera Module 3 capture and autofocus evidence;
10. STOP, watchdog, lease, restart, and torque-off tests;
11. bounded Live Follow only after the ordinary path passes.

Record requested, resolved, and measured angles separately. Raw servo speed is
not degrees per second. A plan receipt is not arrival proof, and arrival is not
visual or object-outcome proof.

## 11. Completion definition

For SIM, you are done when the bridge and gateway run, state and camera work, a
simulated move works, and the dashboard or Codex can connect.

For an existing arm, you are done when the Pi, controller, bus, camera, and
joints work, calibration matches the mechanism, measured moves work, and the
dashboard or Codex can run the requested task.

For a new build, finish the bearing, fastener, print, wiring, power, and assembly
photo details before treating the guide as complete.

## 12. Public handoff

Before pushing:

- run manifest, repository, Python, dashboard, firmware, and script checks for
  the exact worktree/commit;
- review current files and Git history for private data;
- preserve the explicit noncommercial license split in `LICENSING.md`;
- review third-party notices;
- exclude generated builds, runtime state, raw media, backups, tokens, private
  reports, and toolchains;
- label every claim with its actual evidence tier.

Software is available under PolyForm Noncommercial 1.0.0; designs,
documentation, and media use CC BY-NC 4.0. See [Licensing](../LICENSING.md).

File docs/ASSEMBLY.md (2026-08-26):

# Assembly

This is the current build order for co-arm. The 12 printed parts are in
[`hardware/3mf/`](../hardware/3mf/).

## What goes into the build

- Raspberry Pi 4 and Camera Module 3 Wide;
- Waveshare Bus Servo Driver HAT (A);
- three ST3215/STS-family servos and one SC09/SCS-family camera servo;
- the 12 printed parts;
- one large Base bearing;
- heat-set inserts, M3 screws, servo horns, washers, spacers, and cable ties.

The exact bearing details, insert list, screw lengths, and print settings are
still being added.

## 1. Build the Base

1. Start with `co-arm_base_main-body_r01.3mf`. The large Base gear is
   already part of this print.
2. Put `co-arm_base_bearing-bottom_r01.3mf` underneath the large bearing.
3. Fit the bearing into the Base.
4. Put `co-arm_base_shaft-base_r01.3mf` on top of the bearing.
5. Fit the lower-arm servo and
   `co-arm_shoulder_servo-mount_r01.3mf` before bolting
   `co-arm_base_level-2-platform_r01.3mf` to the Shaft Base.
6. Fit `co-arm_base_servo-gear_r01.3mf` to the Base servo and mesh it with the
   large gear. Turn the Base by hand and make sure it moves without a tight
   spot.

The two printed gears make the 4:1 Base reduction. They are part of the arm,
not temporary test pieces.

## 2. Build the arm

1. Attach `co-arm_shoulder_lower-link_r01.3mf` to the lower-arm servo.
2. Fit the next servo at the top of the lower link.
3. Attach `co-arm_elbow_upper-link_r01.3mf`.
4. Close the top-servo area with
   `co-arm_elbow_servo-cover_r01.3mf`.

With torque off, the Shoulder and Elbow can sag. Hold the link or rest it on
something before releasing torque.

## 3. Build the camera end

1. Mount `co-arm_camera_servo-mount_r01.3mf` at the end of the upper link.
2. Put the camera servo inside it.
3. Attach `co-arm_camera_holder_r01.3mf` to the servo.
4. Put the Camera Module 3 Wide in the holder.
5. Close it with `co-arm_camera_cover_r01.3mf`.

## 4. Wire it

The basic chain is:

```text
Camera -> Raspberry Pi
Raspberry Pi -> ESP32 Arm HAT
Arm HAT -> four serial servos
```

Use servo IDs `1 / 2 / 3 / 4` for Base, Shoulder, Elbow, and Camera. Leave
enough cable slack for every joint to move without pulling or entering the Base
gears. The final wiring diagram and power details are still being added; see
[`ELECTRONICS.md`](ELECTRONICS.md) for the current notes.

## 5. First setup

1. Move every joint by hand and check the gears, cables, and hard stops.
2. Mark the physical Base zero.
3. Power and test one servo at a time.
4. Check its ID, direction, and a small move before moving on.
5. Test Base, Shoulder, Elbow, then Camera.
6. Only then try a slow coordinated move.

Continue with [`COMMISSIONING.md`](COMMISSIONING.md) for the software setup and
joint calibration.

## Still to add

- large bearing details;
- heat-set insert and M3 screw list;
- print settings;
- final wiring and power diagram;
- step-by-step assembly photos.

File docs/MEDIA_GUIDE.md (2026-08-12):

# Media guide

The goal is to make the arm understandable without publishing faces, screens,
addresses, account details, serial numbers, QR codes, unrelated desk contents,
or embedded location metadata.

## Intake workflow

1. Copy new originals into untracked `media/raw/`.
2. Keep the originals outside Git history.
3. Review the full frame for personal and device-specific details.
4. Crop or blur anything unrelated to the project.
5. Remove EXIF/XMP/GPS metadata.
6. Export an approved web copy with a descriptive filename.
7. Place it in `media/photos/`, `media/diagrams/`, or `media/video/`.
8. Add a caption and provenance row to the local folder README.
9. Run `python tools/check_repo.py` before staging.

## Photo shot list

### Overview

- front three-quarter view of the complete arm;
- side view showing Base, Shoulder, Elbow, and Camera joints;
- folded/rest pose;
- scale reference that does not reveal personal information.

### Hardware detail

- Base gear and mechanical zero mark;
- each servo label;
- HAT top and bottom, including printed model/revision;
- Raspberry Pi and camera mounting;
- power-supply label;
- physical power-cut or E-stop, if installed.

### Assembly

- parts laid out by stage;
- Base assembly;
- Shoulder and Elbow assembly;
- camera bracket and cable routing;
- wiring and strain relief;
- final mechanical checks.

### Documentation evidence

- clean dashboard overview with private account/device data hidden;
- measured vs. planned 2D scene;
- one wide camera frame and one detail frame, only after desk privacy review.

## Video shot list

- slow physical overview with power off;
- controlled boot and read-only telemetry check;
- one bounded joint movement at a time;
- coordinated move with the sweep visibly clear;
- wide-view to close-view active-perception sequence;
- physical STOP/power-cut demonstration only after its procedure is defined.

## File conventions

- Photos: `YYYY-MM-DD_subject_view_rNN.jpg`
- Diagrams: `subject_diagram_rNN.svg` plus a PNG fallback when useful
- Short clips: `YYYY-MM-DD_subject_rNN.mp4`
- Use lower-case ASCII, hyphens, and a two-digit revision.
- Prefer JPEG/WebP for photos, SVG for diagrams, and H.264 MP4 for short clips.
- Keep individual tracked media comfortably below GitHub's size limit. Use
  Releases or external hosting for long videos.

Do not use Git LFS until the repository owner deliberately chooses it; LFS
changes clone and storage behavior for every contributor.

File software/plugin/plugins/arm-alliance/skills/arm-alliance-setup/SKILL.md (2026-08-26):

---
name: arm-alliance-setup
description: Set up, test, simulate, deploy, or commission the co-arm Raspberry Pi, dashboard, ESP32 Arm HAT, and printable build from a co-arm checkout.
---

# Arm Alliance Setup

Work from a co-arm checkout. Read `AGENTS.md` and
`docs/SETUP_WITH_CODEX.md`, then use `software/SOURCE_INDEX.json` to find the
source.

## Pick the path

- **Source only:** install the locked Python package, run the repository and
  Python checks, then test/build the dashboard.
- **Simulation:** start the Isaac bridge and simulator gateway, then connect the
  dashboard or MCP with `ARM_EXPECTED_BACKEND=sim`.
- **Existing arm:** inspect the Pi, camera, Arm HAT, servo bus, and current
  joints, then deploy or commission the part the user asked for.
- **New build:** use `hardware/3mf/`, `docs/ASSEMBLY.md`, and the BOM. Fill in
  the still-missing bearing, gear-file, insert, screw, print, wiring, and power
  details instead of guessing them.

## Work through it

1. Check the checkout, tool versions, and current Git diff.
2. Run the source checks before involving hardware.
3. For simulation, use the user's Isaac Python, start the bridge/gateway, open
   the dashboard or MCP, and stop it with the repo launcher when finished.
4. For an existing arm, begin with the Pi/camera/controller/bus status that is
   relevant to the request. `/healthz` only says the gateway answered; it does
   not say every servo is online.
5. When the user asks to deploy, flash, restart, calibrate, or move, identify
   the exact source and target, do the requested action, and return the result.
   Do not keep asking for the same permission. Ask only when the target is
   unclear, a real fault blocks it, or a tool needs exact confirmation.
6. Commission one joint at a time before coordinated motion. If the Base loses
   its place, line up the physical zero mark before setting zero again.
7. Configure `arm_mcp` only after choosing the simulator or real gateway and
   setting the matching `ARM_EXPECTED_BACKEND=sim|real`.

Torque off makes Shoulder and Elbow go limp, so hold them if they are raised.
Keep progress updates short and describe the physical result in normal words.

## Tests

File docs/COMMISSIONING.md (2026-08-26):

# Commissioning

This runbook brings a newly assembled co-arm from unpowered hardware to a
documented first motion. It does not authorize flashing or movement by itself;
the operator remains responsible for power isolation, mechanical support, and
the physical work envelope.

Start with [`SETUP_WITH_CODEX.md`](SETUP_WITH_CODEX.md) when a human and Codex
are preparing the checkout or Raspberry Pi together. Return here once the
hardware facts and software release boundary are understood.

Software tests and a successful firmware build do not prove wiring, servo
identity, supply capacity, torque removal, direction, clearance, or motion on
the assembled arm.

## Critical operator inputs

Resolve and record these before the corresponding stage. Do not let software or
an AI guess them.

| Input | Why it is critical |
| --- | --- |
| Exact supply voltage/current rating, fuse, conductor size, and polarity | A logic connection can work while the servo rail is unsafe or undersized |
| Reachable, tested physical servo-power cut | Software STOP depends on powered, functioning electronics |
| Printed model of every servo | STS- and SCS-family devices share a bus but differ in register layout and encoder scale |
| Which physical servo drives each joint | A bus reply does not prove mechanical mapping |
| Base gearbox ratio and a durable physical zero mark | Multi-turn output position cannot be reconstructed after continuity loss without them |
| Safe manual endpoint and inward margin for every joint | Prevents using a hard stop as a calibration instrument |
| Camera/bracket orientation and hardware revision | Determines upright transform, ray convention, and reusable viewpoints |
| Whether the arm is supported during torque release/restart | Shoulder and Elbow can fall when authority expires |

If any answer is not known, stop at the non-motion stage that can still be
completed safely.

## 0. Prepare the work area

1. Remove the servo-rail supply.
2. Support all gravity-loaded links.
3. Clear the full possible sweep and route cables with slack.
4. Install and test a physical servo-power cut with the rail unloaded.
5. Mark the Base mechanical zero visibly and durably.
6. Photograph wiring and labels for the build record, excluding private
   information.
7. Confirm the Pi and ESP32 logic-power arrangement will not back-power another
   host connection.

Do not count a dashboard button as the physical power cut.

## 1. Review the software export

Read [`../software/README.md`](../software/README.md). Confirm that:

- dashboard, backend, gateway, MCP/plugin, simulator, firmware, and operations
  source status is understood;
- local credentials and endpoint configuration are outside Git;
- toolchain versions are recorded locally;
- source tests can be run before deployment;
- the extracted dashboard/backend's standalone packaging limitations are
  accepted.

Run the relevant source tests and firmware compile described by each software
folder. Record the command, toolchain version, commit, and result. This is the
**software proof tier only**.

## 2. Wire with servo power off

The intended control path is:

```text
dashboard / MCP client
-> laptop proxy or direct local MCP configuration
-> authenticated Raspberry Pi gateway
-> ESP32 Arm HAT host UART
-> 1 Mbps TTL servo bus
-> smart servos
```

The Pi camera connects to the Pi and is not in the safety loop. Confirm common
ground, host TX/RX crossover, servo-bus polarity, supply polarity, and connector
orientation against the exact board revision.

Only one host may drive the ESP32 host UART while flashing. Disconnect or
isolate the Pi serial side before connecting a USB flashing host. Keep servo
power off for the flash.

## 3. Build and flash Arm HAT firmware 2.7.2

1. Build the exported ESP32 sketch against its bundled Arm HAT controller
   library using a reviewed local toolchain. Toolchains and generated binaries
   are not committed.
2. Save the build log and artifact hash locally.
3. Confirm the exact target board and flash port.
4. Isolate competing UART hosts.
5. Flash only after explicit operator approval.
6. Disconnect the flashing host or otherwise restore the intended Pi UART
   topology before the controller handshake.

On boot, firmware should begin disarmed and attempt a servo-bus torque-off
broadcast. A boot message saying an attempt was sent is not the same as
addressed torque-off confirmation from every servo.

## 4. Establish a non-motion controller handshake

With the servo rail still off, start the Pi gateway and confirm a compatible,
typed controller handshake. It must report:

- expected protocol and firmware generation;
- disarmed/blocked startup rather than active motion;
- boot torque-off attempt status;
- the watchdog and lease range;
- required capabilities, including native absolute multi-turn support for the
  Base path;
- the expected host-UART and servo-bus configuration.

Do not commit controller identifiers, network addresses, or credential paths to
the public repository.

## 5. Assign and verify servo-bus identities one at a time

Factory servos may share an identifier. Never connect several uncommissioned
same-ID servos and try to repair the collision in software.

For each servo:

1. Remove servo power.
2. Connect exactly one servo to the bus and mechanically unload/support it.
3. Read and photograph the printed model label.
4. Power the rail and perform a bounded scan.
5. Confirm exactly one response.
6. Assign the reference mapping: Base `1`, Shoulder `2`, Elbow `3`, Camera `4`.
7. Power-cycle and scan again before applying a physical label.
8. Remove power before connecting the next servo.

The reference arm uses STS-family behavior for Base/Shoulder/Elbow and
SCS-family behavior for Camera. Do not infer family from a successful ping.

## 6. Assemble the bus and verify readback

With all four labelled servos connected and the arm supported:

1. Power on without requesting torque.
2. Perform a non-motion scan.
3. Refresh state after the scan; a first cached state can lag the bus result.
4. Confirm all expected joints are present and mapped.
5. Confirm torque is `off` or otherwise safely known.
6. Inspect voltage, temperature, moving flag, fault flags, packet age, and Base
   truth/capability.

If the controller disappears after torque has ever been enabled, treat torque
as `unknown` and remove servo power before touching the arm.

## 7. Calibrate each joint with torque off

Keep the arm supported and calibrate one joint at a time.

For each joint:

1. Confirm the physical joint mapping by moving only that joint manually and
   observing which encoder changes.
2. Place it at the chosen neutral/zero and use server-owned **Set zero here**;
   do not send an old browser-cached encoder value.
3. Determine the positive physical direction with a manual torque-off move.
4. Capture comfortable negative and positive endpoints manually.
5. Apply an inward safety margin; never drive into a hard stop.
6. Record encoder scale, direction, gear ratio, and calibrated degree limits.
7. Re-read the saved configuration and its revision.

The Camera servo may use a different encoder scale and byte/register family
from the arm joints. It still needs its own zero and safe travel limits.

## 8. Configure and home the Base absolute frame

The reference Arm HAT 2.7.2 Base path uses ST3215 native Mode-0 absolute
multi-turn operation. The verified reference profile expects:

- Phase register BIT4 enabled (the reference value was `28`);
- resolution register set to `1`;
- internal angle-limit registers cleared for the multi-turn path;
- operating mode `0` (position mode);
- native capability `multi_turn_absolute_v1` visible to the Pi.

Use the typed commissioning workflow that performs torque-off staging,
read-modify-write/readback, and configuration verification. Do not hand-issue
raw register writes from this guide.

Then:

1. Remove/confirm torque off and align the output to the physical Base zero
   mark.
2. Use **Set zero here** to bind the native signed motor frame to output zero.
3. Confirm the Pi reports valid native-frame truth from the same controller
   boot.
4. If continuity becomes unknown at any later time, repeat this physical
   re-home. Never infer an output revolution from a single-turn reading.

## 9. Verify geometry and floor policy without moving

Confirm the configured model matches the assembled revision:

- Base pivot height `60 mm`;
- upper arm `180 mm`;
- Elbow-to-tip distance `220 mm`;
- Shoulder `0 deg` straight up;
- straight arm at Elbow `90 deg`;
- Camera `0 deg` along the forearm, positive down;
- floor guard enabled at the intended floor reference (reference default
  `40 mm`).

Render a measured scene and compare it to the physical arm. A 90-degree frame
error here makes the floor calculation unsafe even if every joint angle is
numerically fresh.

## 10. First controlled motion

Before each first-motion test, confirm the physical power cut, mechanical
support, and clear sweep again.

1. Prepare a very small single-joint plan at low speed.
2. Review measured and planned angles, warnings, and swept clearance.
3. Apply the one-use plan.
4. Read measured state after settling; do not judge success from the apply
   response.
5. STOP immediately for wrong direction, unexpected sound/current, cable pull,
   structural flex, telemetry loss, or motion outside the reviewed sweep.
6. Test return to the starting point before increasing range.

Suggested progression:

1. Camera small positive/negative tilt while the distal assembly is supported.
2. Shoulder small positive/negative motion with the Elbow supported.
3. Elbow small positive/negative motion with the distal link supported.
4. Base zero -> small positive -> zero -> small negative -> zero.
5. Larger single-joint points inside conservative limits.
6. Slow coordinated poses with floor guard and plan/apply.
7. A controlled physical STOP test.

Record requested, resolved, and measured angles separately.

## 11. Commission the camera

1. Capture a fresh frame without motion.
2. Confirm the delivered image is upright.
3. Confirm Camera Module 3 Wide / IMX708 identity and array/profile state. IMX708
   alone does not prove the Wide lens variant.
4. Verify Camera positive physically moves the view downward.
5. Build a Base-`0 deg`, elevated/retracted desk survey through plan/apply.
6. Request autofocus where appropriate, then require same-capture AF/lens
   metadata and visible subject detail; the request alone is not focus proof.
7. Save a named viewpoint only after measured arrival and pixel coverage are
   both verified.
8. Reverify that view after any bracket, camera, geometry, zero, or limit change.

Do not publish an unreviewed desk capture. See [`VISION.md`](VISION.md).

## 12. Commission Live Follow last

Only after ordinary joint motion, feedback, STOP, lease, and floor behavior are
proved should a deliberate REAL Live Follow session be considered. Start with a
small travel envelope. Confirm the separate heartbeat/dead-man path, grouped
Shoulder/Elbow feedback, measured trace, orderly release, and torque-off state.
Raw speed is not degrees per second, and the exported policy rejects
acceleration above `50` rather than silently pretending it was applied.

## 13. Restart and fail-safe checks

Place the arm in a verified clear rest pose or support it mechanically before a
service/controller restart. A restart can outlast the heartbeat and hold lease,
causing a held arm to sag.

Verify separately:

- gateway restart does not command motion;
- controller boot starts disarmed and attempts torque off;
- loss of heartbeat revokes torque authority within the watchdog contract;
- lease expiry removes hold authority;
- deliberate STOP remains latched until inspected reset;
- reset does not resume the old goal;
- Base truth is preserved only when continuity is explicitly proven, otherwise
  re-home is required.

These are live hardware tests. Run them with support, clearance, and a physical
power cut.

## Commissioning record

For each stage, record:

- hardware/CAD revision;
- firmware and software commit/artifact hashes from the actual source package;
- supply and protection configuration;
- confirmed servo labels and joint mapping;
- calibration revision and limits;
- requested/resolved/measured motion;
- voltage, current/load where supported, temperature, faults, and packet loss;
- STOP/lease/watchdog test method and result;
- camera evidence filename after privacy review;
- operator, date, result, and remaining proof debt.

Completion should read: **commissioned for the tested envelope; motion remains
disarmed until explicitly requested**. It must not imply certification or safe
operation outside the recorded configuration.

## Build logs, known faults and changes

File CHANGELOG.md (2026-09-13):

# Changelog

All notable public repository changes will be recorded here.

## Unreleased

- Selected PolyForm Noncommercial 1.0.0 for software and firmware, and
  CC BY-NC 4.0 for designs, documentation, and media. Added full license texts,
  attribution, contribution terms, and Python/dashboard/firmware metadata.
- Prepared the public prototype source release; the full purchased-parts
  schedule and demo media remain follow-up work.
- Fixed Live startup after React StrictMode replay and added locally tested
  recovery Base-reference gates, archive preparation, provenance handling,
  and Windows recovery regressions. Exact-stack physical acceptance remains pending.
- Fixed source-manifest drift between Windows files and committed Git exports,
  and added an LF line-ending release gate with regressions.
- Ported Camera arrival/pursuit tuning, strict dashboard target handling,
  process-stable gateway identity, and response-bound camera provenance with
  boundary and restart-race regressions.
- Added the missing NumPy/headless OpenCV test dependencies so a fresh Python
  environment can collect the simulator camera-policy tests.
- Added a short no-hardware quickstart, existing-arm setup routing, a dated
  release review, and draft release/X copy.
- Documented the remaining portable recovery device-acceptance work after the
  Base-reference, provenance, and fresh-install metadata fixes.
- Rewrote the README around the physical build and why it exists, using the
  same direct voice as Rock and DOT instead of leading with software policy.
- Added all 12 current 3MF parts: both printed Base gears, bearing-bottom piece,
  Shaft Base, Level 2 platform, servo mount/covers, lower and upper links, and
  the camera mount/holder/cover.
- Added the current physical assembly map, one-row-per-part BOM entries, and a
  short list of the bearing, inserts, screws, and print details still needed.
- Made Codex verify whether it is connected to the simulator or the real arm,
  return plain structured results, and avoid repeating a physical write after
  a lost response.
- Made the source index root unambiguous and extended the repository checker to
  cover CI, Dependabot, locked dependencies, and installed-wheel smoke.
- Updated the Python and Pi dependency sets to current patched compatible
  versions, forced the patched dashboard `nanoid`, and added Python/pnpm audit
  gates to CI.
- Packaged the simulator URDF/JSON in the Python wheel, excluded test suites,
  and added a source-isolated installed-wheel smoke with honest dashboard-asset
  failure behavior.
- Corrected the Arm HAT 2.7.2 goal-readback documentation to four attempts with
  5 ms gaps while preserving the distinct compact-feedback retry contract.
- Added clean-checkout CI and weekly Dependabot coverage for Python, Pi
  requirements, pnpm, and GitHub Actions.
- Promoted the repository from a documentation scaffold to an ARM-only source
  export.
- Added the standalone React/Vite Arm dashboard and loopback FastAPI runtime.
- Added the Raspberry Pi gateway, Arm MCP server, core Isaac Sim stack,
  portable Codex plugin, deployment helpers, and focused tests.
- Added Arm HAT `2.7.2`, shared controller libraries, and host-side protocol
  tests.
- Updated the public reference build to Raspberry Pi Camera Module 3 Wide /
  IMX708 and documented the survey/detail autofocus evidence contract.
- Documented bounded Shoulder/Elbow Live Follow without treating raw servo
  settings as measured speed.
- Removed unrelated parent-workspace product/evaluation/runtime branches and
  the superseded three-joint synthetic gateway so the release stays focused on
  the arm, Pi, Arm HAT, Isaac Sim, dashboard, and external agent workflow.
- Reworked the source boundary and privacy checks to exclude credentials,
  runtime state, captures, reports, backups, generated artifacts, and unrelated
  parent-application code.
- Added a canonical source index and deterministic per-file SHA-256 manifest
  with a stale-manifest verification command.
- Kept source/build evidence distinct from previously recorded reference-arm
  evidence; no live hardware verification was performed for this export.
- Replaced the earlier no-license status with explicit noncommercial terms.

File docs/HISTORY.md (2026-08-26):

# Public engineering history

This is a distilled technical history. Failed approaches are included when
they explain the current design, but installation-specific and personal
details have been removed.

## 2026-07-31 to 2026-08-04 — simulator-first foundation

The project established a Raspberry Pi camera/evidence gateway, an ESP32 HAT
protocol, replay and simulation infrastructure, commissioning UI, and a local
dashboard. Early builds and tests proved software paths only; they did not
prove servo motion.

## 2026-08-04 — physical stack connected

The Pi service, camera, direct controller link, and reboot recovery were
observed. The controller was still in an early firmware line and the physical
commissioning path was incomplete.

## 2026-08-05 — bus and telemetry root causes

The primary early motion failure was traced to incorrect ST3215 load decoding:
the load-direction flag is bit 10, not bit 15. The fix removed false collision
interpretation. A separate bus failure was traced to a factory ID collision:
the SC09 camera servo initially shared ID 1 with the Base. It was isolated,
reassigned to ID 4, and the full bus then enumerated IDs 1 through 4 cleanly.

## 2026-08-07 — wide motion, then a reliability limit

An earlier Mode-3 relative-step approach produced real signed Base travel and
coordinated four-joint movement. The software gained STOP/watchdog handling,
floor geometry, hold leases, and richer telemetry. This was meaningful physical
progress, but Mode-3 depended on sampled continuity and step bookkeeping.

## 2026-08-08 — typed AI control and false-zero diagnosis

Codex moved the arm and captured real camera pixels through typed tools. A
serious Base false-zero event was then reproduced: software could report a
plausible coordinate after physical multi-turn truth had been lost. Motion was
paused and the failure was treated as a coordinate-continuity problem rather
than a UI or network glitch.

## 2026-08-09 — recovery and homing work

Atomic homing, Pi/HAT reconnection behavior, diagnostics, and hold-renewal
fixes were developed and deployed in stages. These reduced known failure modes,
but did not make the relative-step method an acceptable final architecture.

## 2026-08-10 — native absolute Base control

Firmware 2.4.0 replaced Mode-3 step bookkeeping with the ST3215's native
Mode-0 signed extended-position coordinate. Configuration became a guarded
read/modify/write/readback sequence. A physical Base readback proved the
extended-position phase bit, resolution, zero limits, operating mode, lock,
and torque-off state. The matching Pi source was deployed, the complete stack
was power-cycled, and the configuration persisted.

The operator then accepted normal zero, positive, negative, and return movement.
This was physical acceptance, not a complete numeric seam or endpoint table.

## 2026-08-10 — Arm Alliance

The arm gained a shared MCP server and bounded Codex integration. Live tools
were separated from project editing authority, and local AI context was
allowlisted rather than copying credentials, transcripts, or an entire agent
home.

## 2026-08-11 — explicit plan/apply and full-resolution vision

Motionless preview and one-use apply contracts were added. Preview resolves
joint targets or planar IK against fresh telemetry, limits, start-pose drift,
and independently timed swept floor clearance. A real preview was generated
without moving the arm. The apply path remains a recorded physical gate.

Camera capture moved to the OV5647's full still resolution. Focus handling now
states the actual optical limit: the installed sensor module is fixed focus.
For it, useful focus comes from choosing standoff and judging visible subject
detail, not pretending software can actuate a lens.

## 2026-08-22 to 2026-08-23 — Camera Module 3 and Live Follow

The reference camera changed to Camera Module 3 Wide / IMX708. Survey/detail
profiles, sensor/array validation, powered autofocus controls, and same-capture
AF evidence were added while retaining OV5647 only as a legacy compatibility
profile.

Shoulder/Elbow Live Follow gained a separate strict heartbeat, bounded grouped
dispatch, exact goal readback, dead-man/lease behavior, and start-relative
travel envelopes. After the installed servos were shown to store acceleration
`50` when a higher value was requested, every current layer adopted `1..50` as
the explicit arm-specific range. Five- and twelve-second unloaded runs then
completed on matching Arm HAT 2.7.2, Pi, and dashboard code. The raw settings
were not treated as calibrated speed.

## 2026-08-24 — ARM-only public source export

The standalone dashboard/backend, Pi gateway, Arm HAT firmware, core Isaac
simulator, MCP/plugin, operations helpers, and focused tests were extracted from
the broader development workspace. Machine-specific configuration, credentials,
runtime data, captures, reports, backups, generated artifacts, and unrelated UI
were excluded. Unrelated product and evaluation additions were then removed to
keep the public package focused on building, simulating, commissioning, and
running the arm. Clean-checkout tests remain source evidence, not a new hardware
verification.

## Current lesson

The project became more reliable whenever it replaced inferred state with
measured state and made evidence explicit: native signed coordinates instead
of reconstructed turns, plan/apply instead of implicit motion, retained source
crops instead of needless recaptures, and visible pixels instead of assuming a
named pose must show the desk.

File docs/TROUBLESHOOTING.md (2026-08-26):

# Troubleshooting

Start by identifying the failed layer. Do not compensate for an unknown state
with a larger move, disabled guard, raw register write, or repeated command.

## Immediate stop conditions

Use STOP or the physical servo-power cut, as appropriate, if the arm moves in
the wrong direction, leaves the reviewed sweep, catches a cable/object, makes
an abnormal sound, reports an electrical fault, loses trustworthy telemetry,
or does not respond to STOP. If torque state becomes `unknown`, remove servo
power before touching the arm.

Support gravity-loaded links before release, restart, reconnect, or manual
repositioning.

## Read-only diagnosis order

1. Gateway process health
2. Controller connection and boot continuity
3. Servo-bus health
4. Non-motion bounded bus scan
5. Refreshed live arm state
6. Required joint freshness, faults, torque, and Base truth
7. Floor guard and calibrated limits
8. Only then, prepare a motionless plan

A gateway health result does not prove the controller or servo bus. A scan can
find devices while an older cached state still says offline; refresh state
before deciding.

## Connection and bus symptoms

| Symptom | Likely layer | Safe checks and response |
| --- | --- | --- |
| Dashboard cannot reach gateway | Local backend, tunnel, gateway service, or credentials | Check each process independently; do not restart a torque-holding arm without support |
| Gateway healthy, controller offline | Host UART, boot order, firmware mismatch, or controller power | Keep servo power/motion off; verify one host owns UART, then use the bounded reconnect path |
| Controller online, servo bus offline | Servo power, bus wiring/polarity, collision, noise, or wrong baud | Remove power, inspect wiring, reconnect one labelled servo, run bounded scan |
| Scan finds fewer/more devices | Disconnected servo, duplicate ID, unexpected device | Power off and isolate one servo; never rewrite IDs on a populated ambiguous bus |
| Torque says `unknown` | Readback missing, controller disappeared, or off confirmation failed | Remove servo power; do not touch until electrical state is known |
| State looks stale immediately after scan/reconnect | Cached telemetry has not refreshed | Wait for a new generation and read state again; do not move from the old snapshot |

## STOP, watchdog, and lease symptoms

| Symptom / error | Meaning | Response |
| --- | --- | --- |
| `STOPPED` | STOP is latched or controller reports stopped | Inspect the physical cause. Clear only on explicit operator decision after torque-off checks |
| `NO_TORQUE_LEASE` | Motion arrived without active authority, often after a delay or restart | Do not bypass it. Let the Pi retake a fresh hold only after state/clearance are rechecked |
| Hold drops during motion | Heartbeat/serial starvation, lease expiry, process interruption, or electrical fault | Support/STOP, inspect connection and packet timing, then replan from measured position |
| Arm moves again after authority returns | A stale goal was retained somewhere | STOP and power-cut if needed. The current Pi clears outstanding goals on deliberate STOP; verify deployed version before retesting |
| STOP will not clear | No fresh heartbeat, torque-off not confirmed, or an operator STOP still intentionally held | Resolve heartbeat/readback; never loop reset requests blindly |

Current reference limits are a 750 ms firmware watchdog, 100..2000 ms lease
range, a 2000 ms Pi hold renewed around 800 ms, and an approximately 200 ms Pi
heartbeat. Treat a mismatch between source and live handshake as deployment
drift.

## Plan/apply symptoms

| Symptom / message | Cause | Response |
| --- | --- | --- |
| Plan unavailable, expired, or already used | Plan exceeded its current 30 s lifetime or was consumed | Read state and prepare a new plan |
| Digest mismatch | Applied data is not the exact reviewed proposal | Discard it and plan again; never edit the digest or targets |
| Controller boot changed | Preview belongs to an older controller continuity frame | Re-read state; re-home Base if truth is not proven; plan again |
| Configuration changed | Calibration, limits, geometry, or floor policy differs from preview | Review the new configuration and plan again |
| Joint moved after preview | Start pose drift exceeded current 2 deg tolerance | Wait for settle or investigate unexpected motion, then replan |
| Earlier move is still settling | An outstanding bounded goal has not closed/expired | Read measured state; do not stack another plan |
| Fresh telemetry required | Needed joint packet, heartbeat, or Base odometer evidence is stale | Wait for a new measured generation; fix connection if it stays stale |
| Sweep crosses floor | Any independently timed Shoulder/Elbow combination can go below the allowed plane | Choose a different pose or safe waypoint. Do not disable the guard as an agent workaround |
| Direct move was clamped | Calibrated limit or floor boundary changed the command | Read the returned reason and measured state; revise the request rather than repeatedly pushing the boundary |

Plan/apply success proves command acceptance. If measured state differs after
settling, diagnose arrival rather than declaring the destination reached.

## Base multi-turn symptoms

### Base angle is numerically plausible but physically one or more turns wrong

Treat this as lost revolution continuity. STOP, support the arm, remove/confirm
torque off, align the physical Base zero mark, and use **Set zero here**. Never
choose an output revolution from a single-turn reading alone.

### `ODOMETER_UNAVAILABLE`, invalid Base truth, or missing native capability

Do not move Base. Verify Arm HAT 2.7.2/native capability, stable controller boot,
fresh native-frame evidence, Mode 0, and the verified multi-turn
configuration. Re-home if continuity cannot be proven.

### `MODE_NOT_POSITION`

Keep torque off. Use the typed Base configuration/restore workflow, which
verifies mode and related registers. Do not improvise raw writes while the arm
is assembled or energized.

### Base reaches the opposite or stale destination

STOP. Confirm that the deployed stack uses one native absolute destination,
not an older relative-step implementation. Check gateway, firmware, and client
versions separately; source changes do not update running processes.

## Floor and geometry symptoms

### Scene is rotated or height is obviously wrong

Verify the servo-to-model offsets: Shoulder `+90 deg`, Elbow `-90 deg`. Shoulder
servo zero must draw straight up, and Shoulder `0` plus Elbow `90` must draw a
straight arm. Confirm 60/180/220 mm geometry and the correct calibration.

### Guard clamps a physically high pose

Check fresh Shoulder/Elbow measurements, direction, zero, offsets, link lengths,
and floor reference. Do not lower the floor value until the model matches the
physical arm.

### Destination is above the floor but plan is refused

The intermediate independently timed sweep may cross the plane even when both
endpoints are safe. Inspect lowest swept clearance and use a safe waypoint.

### Base or Camera was clamped and message mentions travel

Those joints do not affect side-view floor height. Their clamp comes from the
joint's calibrated range; fix the target or calibration evidence, not the floor
guard.

## Camera and vision symptoms

| Symptom | Diagnosis | Response |
| --- | --- | --- |
| Image upside down | Pi transform missing or a second transform was applied | Verify exactly one 180-degree transform in the camera provider |
| Capture succeeds but UI image fails | Browser/object-URL/proxy loading stage, not shutter | Preserve the capture error boundary and debug the display path separately |
| Subject absent after moving | Target pose did not guarantee framing | Verify measured arrival, inspect scene ray, then make a bounded coordinated correction |
| Survey does not cover desk | Stored/guessed viewpoint or current geometry differs | Rebuild the Base-0 elevated survey from live state and pixels |
| Closer frame is softer | AF has not settled, macro/normal range is wrong, or standoff is unsuitable | Check same-frame AF/lens metadata and visible subject detail; change focus range or standoff |
| `FocusFoM` rises but subject is worse | Background texture dominates whole-frame score | Trust subject ROI readability and edges |
| AF is `configured` but not `focused` | Control request has no same-frame focus proof | Require valid capture AF metadata and improved subject detail |
| Detail crop source unavailable | Bounded retained-frame history expired or was not saved | Take a new survey; do not reuse an old runtime identifier |
| Timestamp looks old | Wall clock may be wrong or frame may be stale | Capture two comparison frames and inspect changing content/monotonic age |

## Source, deployment, and UI symptoms

- **Tests pass but hardware behaves differently:** tests are software proof.
  Verify which firmware, gateway, MCP server, and frontend bundle are actually
  running.
- **A new MCP tool is missing:** start a new client task/session after installing
  or updating local MCP configuration. Existing tasks do not hot-load tools.
- **Gateway edit has no effect:** deploy the reviewed package and restart the
  Pi service only after the arm is supported or in a verified clear rest pose.
- **MCP edit has no effect:** restart the MCP process/new task; the Pi service is
  a separate process.
- **Dashboard will not build:** work from `software/dashboard/`, use the pinned
  package manager/lockfile, and distinguish dependency-install failure from a
  TypeScript, test, or Vite failure.
- **Backend cannot find the frontend:** build the dashboard first and confirm
  the standalone runtime's static-directory path. Do not point it at a broader
  private application as a shortcut.
- **Agent tools are unavailable:** confirm the co-arm Python environment is the
  interpreter used by MCP, start a new task after plugin/config changes, and
  verify the selected SIM or REAL URL/token-file pair. This is separate from
  dashboard or gateway health.

## What to capture in a bug report

Include only privacy-safe data:

- commit/artifact versions for each running layer;
- operation and exact public error code/message;
- whether motion occurred;
- controller/bus/STOP/floor/torque trust states, with live identifiers removed;
- requested, resolved, and measured angles only when sharing them is safe;
- calibration and hardware revision;
- redacted photo/video if it materially proves the symptom;
- source-test, build, deployment, live telemetry, and pixel evidence as separate
  sections.

Do not include gateway credentials, private addresses/paths, account/session
state, controller/session/frame identifiers, or unrelated desk content.

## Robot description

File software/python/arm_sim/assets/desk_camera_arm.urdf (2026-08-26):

<?xml version="1.0"?>
<!--
  Primitive simulation seed for the four-axis desk camera arm.

  Measured kinematic lengths come from robot_gateway/simple_arm_api.py.  The
  primitive shell sizes, masses, inertias, damping, effort and velocity limits
  are deliberately provisional; arm_sim/config/arm_model.json is the source of
  truth for that evidence boundary.

  URDF coordinates use metres, kilograms, radians, x-forward, y-left, z-up.
  The four revolute joint positions are intentionally the real servo degrees
  converted directly to radians (no hidden zero offset):
    * Shoulder 0: upper arm points straight up.
    * Elbow 0 at Shoulder 0: forearm points forward; Elbow 90 is straight up.
    * Camera 0: optical axis points along the forearm; positive aims down.
-->
<robot name="desk_camera_arm_v0">
  <material name="base_dark">
    <color rgba="0.10 0.12 0.15 1.0"/>
  </material>
  <material name="arm_blue">
    <color rgba="0.16 0.45 0.78 1.0"/>
  </material>
  <material name="joint_silver">
    <color rgba="0.56 0.60 0.66 1.0"/>
  </material>
  <material name="camera_black">
    <color rgba="0.025 0.03 0.04 1.0"/>
  </material>

  <!-- Empty anchoring link makes this asset explicitly fixed-base. -->
  <link name="world"/>

  <link name="base_link">
    <visual>
      <origin xyz="0 0 0.030" rpy="0 0 0"/>
      <geometry><cylinder radius="0.055" length="0.060"/></geometry>
      <material name="base_dark"/>
    </visual>
    <collision>
      <origin xyz="0 0 0.030" rpy="0 0 0"/>
      <geometry><cylinder radius="0.055" length="0.060"/></geometry>
    </collision>
    <inertial>
      <origin xyz="0 0 0.030" rpy="0 0 0"/>
      <mass value="1.0"/>
      <inertia ixx="0.00105625" ixy="0" ixz="0" iyy="0.00105625" iyz="0" izz="0.0015125"/>
    </inertial>
  </link>

  <joint name="base_fixed_joint" type="fixed">
    <parent link="world"/>
    <child link="base_link"/>
    <origin xyz="0 0 0" rpy="0 0 0"/>
  </joint>

  <link name="shoulder_mount_link">
    <visual>
      <origin xyz="0 0 0" rpy="0 0 0"/>
      <geometry><box size="0.080 0.080 0.060"/></geometry>
      <material name="joint_silver"/>
    </visual>
    <collision>
      <origin xyz="0 0 0" rpy="0 0 0"/>
      <geometry><box size="0.080 0.080 0.060"/></geometry>
    </collision>
    <inertial>
      <origin xyz="0 0 0" rpy="0 0 0"/>
      <mass value="0.35"/>
      <inertia ixx="0.000291667" ixy="0" ixz="0" iyy="0.000291667" iyz="0" izz="0.000373333"/>
    </inertial>
  </link>

  <joint name="base_yaw_joint" type="revolute">
    <parent link="base_link"/>
    <child link="shoulder_mount_link"/>
    <!-- Measured physical Base/Shoulder pivot height: 60 mm. -->
    <origin xyz="0 0 0.060" rpy="0 0 0"/>
    <axis xyz="0 0 1"/>
    <limit lower="-3.141592654" upper="3.141592654" effort="20.0" velocity="0.523599"/>
    <dynamics damping="0.30" friction="0.05"/>
  </joint>

  <link name="upper_arm_link">
    <visual>
      <origin xyz="0 0 0.090" rpy="0 0 0"/>
      <geometry><box size="0.035 0.040 0.180"/></geometry>
      <material name="arm_blue"/>
    </visual>
    <collision>
      <origin xyz="0 0 0.090" rpy="0 0 0"/>
      <geometry><box size="0.035 0.040 0.180"/></geometry>
    </collision>
    <inertial>
      <origin xyz="0 0 0.090" rpy="0 0 0"/>
      <mass value="0.30"/>
      <inertia ixx="0.00085" ixy="0" ixz="0" iyy="0.000840625" iyz="0" izz="0.000070625"/>
    </inertial>
  </link>

  <joint name="shoulder_pitch_joint" type="revolute">
    <parent link="shoulder_mount_link"/>
    <child link="upper_arm_link"/>
    <origin xyz="0 0 0" rpy="0 0 0"/>
    <!-- -Y makes positive servo angle move the vertical link toward -X. -->
    <axis xyz="0 -1 0"/>
    <limit lower="-1.570796327" upper="1.570796327" effort="20.0" velocity="0.436332"/>
    <dynamics damping="0.35" friction="0.06"/>
  </joint>

  <link name="forearm_link">
    <visual>
      <origin xyz="0.090 0 0" rpy="0 0 0"/>
      <geometry><box size="0.180 0.035 0.035"/></geometry>
      <material name="arm_blue"/>
    </visual>
    <collision>
      <origin xyz="0.090 0 0" rpy="0 0 0"/>
      <geometry><box size="0.180 0.035 0.035"/></geometry>
    </collision>
    <inertial>
      <origin xyz="0.090 0 0" rpy="0 0 0"/>
      <mass value="0.25"/>
      <inertia ixx="0.000051042" ixy="0" ixz="0" iyy="0.000700521" iyz="0" izz="0.000700521"/>
    </inertial>
  </link>

  <joint name="elbow_pitch_joint" type="revolute">
    <parent link="upper_arm_link"/>
    <child link="forearm_link"/>
    <!-- Measured upper-arm pivot-to-pivot length: 180 mm. -->
    <origin xyz="0 0 0.180" rpy="0 0 0"/>
    <axis xyz="0 -1 0"/>
    <limit lower="-1.570796327" upper="1.570796327" effort="20.0" velocity="0.436332"/>
    <dynamics damping="0.30" friction="0.05"/>
  </joint>

  <!--
    A fixed 40 mm extension keeps the modeled camera pivot at the same
    elbow-to-tip distance (180 + 40 = 220 mm) used by the real floor guard.
    Camera pitch therefore changes aim, not the arm's kinematic endpoint.
  -->
  <link name="tool_offset_link">
    <visual>
      <origin xyz="0.020 0 0" rpy="0 0 0"/>
      <geometry><box size="0.040 0.030 0.030"/></geometry>
      <material name="joint_silver"/>
    </visual>
    <collision>
      <origin xyz="0.020 0 0" rpy="0 0 0"/>
      <geometry><box size="0.040 0.030 0.030"/></geometry>
    </collision>
    <inertial>
      <origin xyz="0.020 0 0" rpy="0 0 0"/>
      <mass value="0.08"/>
      <inertia ixx="0.000012" ixy="0" ixz="0" iyy="0.000016667" iyz="0" izz="0.000016667"/>
    </inertial>
  </link>

  <joint name="tool_offset_fixed_joint" type="fixed">
    <parent link="forearm_link"/>
    <child link="tool_offset_link"/>
    <!-- Measured forearm length: 180 mm. -->
    <origin xyz="0.180 0 0" rpy="0 0 0"/>
  </joint>

  <link name="camera_link">
    <visual>
      <origin xyz="0 0 0" rpy="0 0 0"/>
      <geometry><box size="0.025 0.040 0.030"/></geometry>
      <material name="camera_black"/>
    </visual>
    <collision>
      <origin xyz="0 0 0" rpy="0 0 0"/>
      <geometry><box size="0.025 0.040 0.030"/></geometry>
    </collision>
    <inertial>
      <origin xyz="0 0 0" rpy="0 0 0"/>
      <mass value="0.06"/>
      <inertia ixx="0.0000125" ixy="0" ixz="0" iyy="0.000007625" iyz="0" izz="0.000011125"/>
    </inertial>
  </link>

  <joint name="camera_pitch_joint" type="revolute">
    <parent link="tool_offset_link"/>
    <child link="camera_link"/>
    <!-- Measured tool/camera offset: 40 mm beyond the forearm. -->
    <origin xyz="0.040 0 0" rpy="0 0 0"/>
    <!-- +Y makes positive Camera servo angle aim below the forearm. -->
    <axis xyz="0 1 0"/>
    <limit lower="-1.570796327" upper="1.570796327" effort="4.0" velocity="0.872665"/>
    <dynamics damping="0.08" friction="0.02"/>
  </joint>

  <!-- ROS/Isaac optical convention: +Z forward, +X right, +Y down. -->
  <link name="camera_optical_frame"/>
  <joint name="camera_optical_joint" type="fixed">
    <parent link="camera_link"/>
    <child link="camera_optical_frame"/>
    <!-- Put the provisional lens origin beyond the 25 mm camera-body shell. -->
    <origin xyz="0.020 0 0" rpy="-1.570796327 0 -1.570796327"/>
  </joint>
</robot>

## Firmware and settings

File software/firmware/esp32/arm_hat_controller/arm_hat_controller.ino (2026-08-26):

#include <Arduino.h>
#include <ArmHatController.h>

armhat::ArmHatRuntime armController(Serial, Serial1);

void setup() {
  // UART0 is the polling-only host link. Do not attach both the Pi GPIO UART
  // and the ESP32 Type-C USB serial bridge at the same time.
  Serial.begin(115200);
  armController.begin(1000000, 18, 19);
}

void loop() {
  armController.poll();
  armController.tick();
  // Read native signed absolute feedback for tracked servos. Runs after safety
  // supervision and never inside a host command, so it only adds bus reads.
  armController.sampleOdometers();
  // Safety supervision runs every millisecond while the idle task gets CPU
  // time instead of leaving this core in a full-speed busy loop.
  delay(1);
}

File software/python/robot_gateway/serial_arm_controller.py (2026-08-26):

"""Strict A1 serial transport for the dedicated ESP32 arm controller."""

from __future__ import annotations

from copy import deepcopy
import json
import math
import re
import secrets
import threading
import time
from typing import Callable, Protocol

from .arm_controller import (
    ControllerCommandError,
    ControllerProtocolError,
    ControllerTransportError,
    ControllerUnavailableError,
    MoveSetTuple,
    _normalize_follow_read,
    _normalize_follow_set,
    _normalize_move_set,
)


PROTOCOL_TAG = "A1"
# Mirrors the firmware's MAX_HOLD_SERVOS (4 as of arm-hat-2.0.0). Named, and
# used on both the send and the parse side, because it was previously written
# out as a bare 3 in two places: raising the firmware and the API to four left
# those behind, so holding all four joints was refused with "at most three
# servos can be held" -- surfaced to the browser as "gateway unavailable".
MAX_HOLD_SERVOS = 4
PROTOCOL_VERSION = 1
DEFAULT_BAUDRATE = 115_200
DEFAULT_TIMEOUT_SECONDS = 0.5
HEARTBEAT_INTERVAL_SECONDS = 0.2
# Mirrors ODOMETER_MAX_REVOLUTIONS in the HAT firmware.
ODOMETER_MAX_REVOLUTIONS = 64

# The HAT owns the ST3215's counted coordinate. The Pi sends one signed absolute
# destination; the HAT compares it with live encoder samples and closes the move
# in Mode 0. PRESENT POSITION still wraps at 4095, so only ODO_READ may be used
# as multi-turn truth.
MULTI_TURN_GOAL_LIMIT = 30_719
# Mode 0 is the native absolute path. Mode 3 remains parse-compatible with an
# older HAT, but the service capability gate never drives Base through it.
HOLDING_MODES = frozenset({0, 3})
# The disabled diagnostic register-write operation still has a six-token A1
# parser budget; its id and address leave room for at most four data bytes.
MAX_REGISTER_WRITE_VALUES = 4
_REGISTER_ACCELERATION = 41
_REGISTER_PHASE = 18
_REGISTER_RESOLUTION = 30
_REGISTER_OPERATING_MODE = 33
_REGISTER_TORQUE_ENABLE = 40
_REGISTER_LOCK = 55
_REGISTER_PRESENT_POSITION = 56
_STS_PHASE_EXTENDED_POSITION = 0x10
_INSPECTION_SAFE_OPERATIONS = frozenset(
    {
        "CAPTURE",
        "HEARTBEAT",
        "ODO_READ",
        "REG_READ",
        "RESET",
        "SCAN",
        "STATUS",
        "STOP",
        "TORQUE_OFF",
    }
)
_MOVE_SET_PREFLIGHT_ERRORS = frozenset(
    {
        "BAD_ARGS",
        "HEARTBEAT_STALE",
        "NO_TORQUE_LEASE",
        "ODOMETER_UNAVAILABLE",
        "OUT_OF_RANGE",
        "SERVO_ERROR",
        "STOPPED",
        "UNSUPPORTED",
    }
)
_FOLLOW_READ_ERRORS = frozenset(
    {
        "BAD_ARGS",
        "FEEDBACK_UNAVAILABLE",
        "HEARTBEAT_STALE",
        "NO_TORQUE_LEASE",
        "OUT_OF_RANGE",
        "SERVO_ERROR",
        "STOPPED",
        "UNSUPPORTED",
    }
)
_CONTROLLER_STOP_REASONS = frozenset(
    {"MOVE_SET_FAILED", "EXPLICIT_STOP", "SAFETY_FAULT"}
)
_REGISTER_GOAL_POSITION = 42
_REGISTER_GOAL_SPEED = 46
_REGISTER_MIN_ANGLE = 9
_REGISTER_MAX_ANGLE = 11

# Motion policy for this arm, pushed to the controller on connect. These are the
# knobs that previously required a firmware flash to change. Each is clamped by a
# hard ceiling on the controller; the fail-safes (watchdog, torque lease, STOP
# latch, boot torque-off) are deliberately NOT settable from here.
MOTION_POLICY: dict[str, int] = {
    # Tuned for a bench arm an operator is standing next to with a STOP button,
    # not for an industrial cell. The fail-safes below still hold: watchdog,
    # torque lease, STOP latch, boot torque-off.
    "MAX_DELTA": 512,
    "MOTION_BUDGET_MS": 600,
    # A geared joint will not settle to a couple of ticks; this is a property of
    # the arm, so it belongs here rather than in the controller binary.
    "POS_TOLERANCE": 24,
    "EXEC_TIMEOUT_MS": 600,
    # MAX_SPEED gates MOVE as well as NUDGE, and MOVE is what the drive bar uses.
    # At 256 a full motor turn takes ~19 s, which reads as "the bar does nothing".
    # 2400 puts it near 2 s, which is what a drag is expected to feel like.
    "MAX_SPEED": 2400,
    # The installed ST3215 Shoulder and Elbow servos clamp register 41 to 50.
    # Advertising a larger value makes strict goal readback correctly reject
    # the command after dispatch, so 50 is the honest device limit.
    "MAX_ACCEL": 50,
    # A moving servo returns the odd transient status byte; revoking authority on
    # the first one latched STOP on every real move.
    "SUPERVISION_TOLERANCE": 6,
}
MAX_REQUEST_BYTES = 256
MAX_RESPONSE_BYTES = 4096
OPERATION_TIMEOUT_SECONDS = {
    # A 0..253 scan includes the full ping census, torque-off reconciliation,
    # telemetry refreshes, and JSON transmission. Keep it bounded without
    # mistaking a slow but valid commissioning exchange for a dead UART.
    "SCAN": 4.0,
    # ID assignment performs the full census plus verified EEPROM writes.
    "ASSIGN_ID": 1.5,
    # Position-mode restore performs the same census plus verified EEPROM writes.
    "SET_POSITION_MODE": 1.5,
    # Firmware bounds the physical nudge wait itself, then verifies readback
    # and torque-off before replying.
    "EXECUTE_NUDGE": 1.25,
    # Up to four addressed goal readbacks follow one or two no-ACK family
    # broadcasts; leave bounded headroom above the ordinary UART timeout.
    "MOVE_SET": 0.75,
    # Exactly two goal readbacks plus fresh telemetry/torque/mode reads.
    "FOLLOW_SET": 0.75,
    "FOLLOW_READ": 0.75,
}
_SAFE_OPERATION = re.compile(r"^[A-Z][A-Z0-9_]{0,31}$")
_SAFE_ERROR = re.compile(r"^[A-Z][A-Z0-9_]{0,31}$")
_SAFE_IDENTITY = re.compile(r"^[A-Za-z0-9][A-Za-z0-9._-]{0,127}$")
_SAFE_PROPOSAL = re.compile(r"^[A-Za-z0-9_-]{8,128}$")


class SerialPort(Protocol):
    is_open: bool

    def write(self, payload: bytes) -> int: ...

    def flush(self) -> None: ...

    def reset_input_buffer(self) -> None: ...

    def readline(self, size: int = -1) -> bytes: ...

    def close(self) -> None: ...


SerialFactory = Callable[..., SerialPort]


def _default_serial_factory(**kwargs: object) -> SerialPort:
    try:
        import serial  # type: ignore[import-not-found]
    except ImportError:
        raise ControllerUnavailableError("serial support is unavailable") from None
    return serial.Serial(**kwargs)


def _reject_constant(_: str) -> None:
    raise ValueError("non-finite JSON number")


def _object_without_duplicates(pairs: list[tuple[str, object]]) -> dict[str, object]:
    result: dict[str, object] = {}
    for key, value in pairs:
        if key in result:
            raise ValueError("duplicate JSON key")
        result[key] = value
    return result


def _integer(value: object, *, minimum: int, maximum: int, name: str) -> int:
    if isinstance(value, bool) or not isinstance(value, int):
        raise ControllerProtocolError(f"invalid {name}")
    if not minimum <= value <= maximum:
        raise ControllerProtocolError(f"invalid {name}")
    return value
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

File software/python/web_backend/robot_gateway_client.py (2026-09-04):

"""Narrow server-side client for the loopback robot gateway.

The browser never supplies an upstream URL/path and never receives the bearer token.
"""

from __future__ import annotations

from dataclasses import dataclass
import hashlib
import ipaddress
import json
import math
from pathlib import Path
import re
import secrets
from typing import Annotated, Literal
from urllib.parse import urlsplit

import httpx
from pydantic import BaseModel, ConfigDict, Field, field_validator, model_validator


MAX_REQUEST_BYTES = 65_536
MAX_RESPONSE_BYTES = 262_144
MAX_CAMERA_FRAME_BYTES = 16 * 1024 * 1024
CAMERA_CAPTURE_READ_TIMEOUT_SECONDS = 20.0
LIVE_FOLLOW_START_TIMEOUT_MS_MAX = 1_500
LIVE_FOLLOW_ADMISSION_READ_TIMEOUT_SECONDS = 2.0
LIVE_FOLLOW_ADMISSION_STAGE_TIMEOUT_SECONDS = 0.5
_CAMERA_CAPTURE_PROFILES = frozenset({"survey", "detail"})
_REAL_CAMERA_IDENTITY_CONFIDENCE = frozenset(
    {"configured_candidate", "driver_reported"}
)
_ALLOWED_CALLS = frozenset(
    {
        ("GET", "/healthz"),
        ("GET", "/api/camera/status"),
        ("GET", "/api/camera/observations/latest"),
        ("POST", "/api/camera/captures"),
        ("POST", "/api/camera/autofocus"),
        ("GET", "/api/robot/physical/arm/status"),
        ("POST", "/api/robot/physical/arm/controller/reconnect"),
        ("POST", "/api/robot/physical/arm/bus/scan"),
        ("POST", "/api/robot/physical/arm/servos/assign-id"),
        ("POST", "/api/robot/physical/arm/servos/set-position-mode"),
        ("POST", "/api/robot/physical/arm/servos/capture"),
        ("POST", "/api/robot/physical/arm/servos/move"),
        ("POST", "/api/robot/physical/arm/servos/registers/read"),
        ("POST", "/api/robot/physical/arm/servos/odometer/zero"),
        ("POST", "/api/robot/physical/arm/servos/odometer/read"),
        ("POST", "/api/robot/physical/arm/servos/torque-lease"),
        ("POST", "/api/robot/physical/arm/servos/hold-set"),
        ("POST", "/api/robot/physical/arm/servos/torque-off"),
        ("POST", "/api/robot/physical/arm/tests/prepare-nudge"),
        ("POST", "/api/robot/physical/arm/tests/execute-nudge"),
        ("POST", "/api/robot/physical/arm/stop"),
        ("POST", "/api/robot/physical/arm/reset"),
        ("GET", "/api/robot/physical/arm/calibration/profile"),
        ("POST", "/api/robot/physical/arm/calibration/profile"),
        # The simple arm: four numbers per joint, clamped once on the Pi.
        ("GET", "/api/robot/arm/state"),
        ("POST", "/api/robot/arm/scan"),
        ("POST", "/api/robot/arm/torque"),
        ("POST", "/api/robot/arm/servo-id"),
        ("POST", "/api/robot/arm/target"),
        ("POST", "/api/robot/arm/live-follow/start"),
        ("POST", "/api/robot/arm/live-follow/start/cancel"),
        ("POST", "/api/robot/arm/live-follow/frame"),
        ("POST", "/api/robot/arm/live-follow/heartbeat"),
        ("POST", "/api/robot/arm/live-follow/end"),
        ("POST", "/api/robot/arm/plans/preview"),
        ("POST", "/api/robot/arm/plans/execute"),
        ("POST", "/api/robot/arm/sequences/preview"),
        ("POST", "/api/robot/arm/sequences/execute"),
        ("POST", "/api/robot/arm/sequences/execute-and-capture"),
        ("POST", "/api/robot/arm/stop"),
        ("POST", "/api/robot/arm/clear-stop"),
        # Generated across every joint rather than hand-listed. Written out one
        # by one, this stopped at joint_3 while the router, the request models
        # and the gateway had all moved to four -- so every camera calibrate and
        # target 404ed here, at the one hop with no reason to know about it.
        *(
            ("POST", f"/api/robot/arm/joints/{joint}/{action}")
            for joint in ("joint_1", "joint_2", "joint_3", "joint_4")
            for action in ("calibrate", "target")
        ),
    }
)
_PROFILE_HASH_PATTERN = r"^sha256:[0-9a-f]{64}$"
_CAMERA_CONTENT_SHA_PATTERN = re.compile(r"^sha256:[0-9a-f]{64}$")
_CAMERA_SHA_PATTERN = re.compile(r"^[0-9a-f]{64}$")
_SAFE_FRAME_ID = re.compile(r"^[A-Za-z0-9_-]{1,128}$")
_BACKEND_INSTANCE_PATTERN = re.compile(r"^[A-Za-z0-9_.:-]{8,256}$")
_GATEWAY_INSTANCE_PATTERN = re.compile(
    r"^gateway:[A-Za-z0-9][A-Za-z0-9_.-]{7,247}$"
)
_GATEWAY_INSTANCE_HEADER = "x-robot-gateway-instance"


class RobotGatewayConfigurationError(ValueError):
    """Safe-to-display local proxy configuration failure."""


class RobotGatewayError(RuntimeError):
    """A sanitized upstream failure with a browser-safe status code."""

    def __init__(self, message: str, *, status_code: int) -> None:
        super().__init__(message)
        self.status_code = status_code


@dataclass(frozen=True, slots=True)
class CameraFrameResponse:
    content: bytes
    media_type: str
    headers: dict[str, str]


class StrictModel(BaseModel):
    model_config = ConfigDict(extra="forbid", strict=True)


def _finite(value: object, name: str) -> float:
    if isinstance(value, bool) or not isinstance(value, (int, float)):
        raise ValueError(f"{name} must be a JSON number")
    number = float(value)
    if not math.isfinite(number):
        raise ValueError(f"{name} must be finite")
    return number


class ArmGeometry(StrictModel):
    baseHeightMm: float
    upperArmMm: float
    forearmMm: float
    toolOffsetMm: float

    @field_validator("baseHeightMm", "upperArmMm", "forearmMm", "toolOffsetMm", mode="before")
    @classmethod
    def finite_geometry(cls, value: object, info: object) -> float:
        number = _finite(value, getattr(info, "field_name", "geometry"))
        if not 0.0 < number <= 1000.0:
            raise ValueError("geometry measurement must be above 0 and at most 1000 mm")
        return number

    @model_validator(mode="after")
    def combined_forearm_is_supported(self) -> "ArmGeometry":
        if self.forearmMm + self.toolOffsetMm > 1000.0:
            raise ValueError("combined forearm and tool offset must not exceed 1000 mm")
        return self


JointId = Literal["joint_1", "joint_2", "joint_3"]
LogicalName = Literal["base_yaw", "shoulder_pitch", "elbow_pitch"]
RawPosition = Annotated[int, Field(strict=True, ge=0, le=4095)]


class SimpleArmPlanTargets(StrictModel):
    joint_1: Annotated[float, Field(ge=-3600, le=3600)] | None = None
    joint_2: Annotated[float, Field(ge=-3600, le=3600)] | None = None
    joint_3: Annotated[float, Field(ge=-3600, le=3600)] | None = None
    joint_4: Annotated[float, Field(ge=-3600, le=3600)] | None = None


class SimpleArmLiveFollowJointSettings(StrictModel):
    speed: Annotated[int, Field(strict=True, ge=1, le=2400)]
    accel: Annotated[int, Field(strict=True, ge=1, le=50)]
    maxDeltaDegrees: Annotated[
        int, Field(strict=True, ge=1, le=90)
    ] = 30
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

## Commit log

2026-08-12 Document the co-arm reference build
    [bom.csv]
2026-08-13 Add guided Codex setup flow
2026-08-26 chore: checkpoint current ARM workspace
    [bom.csv, co-arm_base_bearing-bottom_r01.3mf, co-arm_base_level-2-platform_r01.3mf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]
2026-09-04 Harden camera behavior and verify the co-arm release candidate
2026-09-13 License co-arm for noncommercial use and prepare public prototype source
